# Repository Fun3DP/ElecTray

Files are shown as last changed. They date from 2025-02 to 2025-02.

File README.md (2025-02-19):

<p align="center">
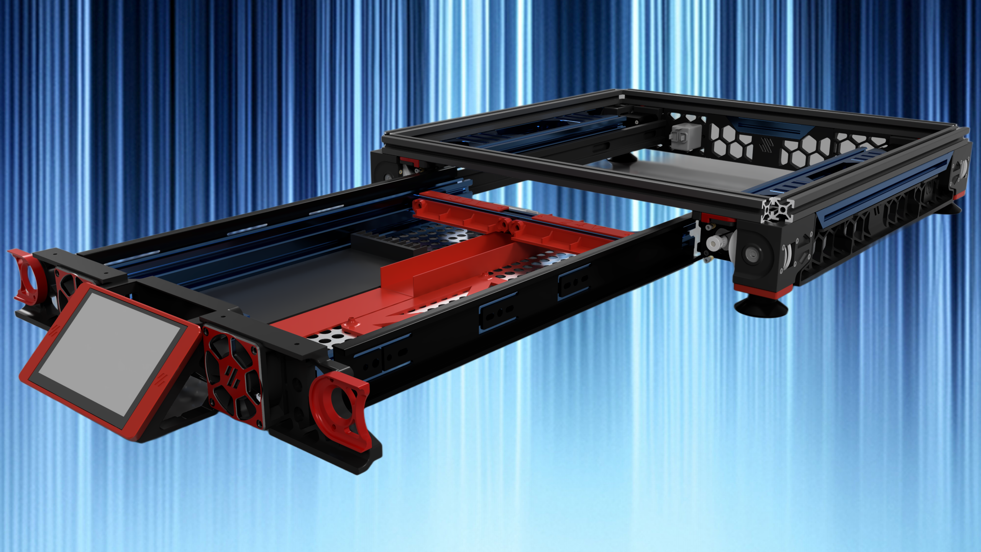
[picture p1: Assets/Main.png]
ElecTray
  
</p>

<p align="center"><b>A drawer mod for the Voron 2.4's electronic components (350mm only)</b>
</p>

<br>

<table>
<tr>
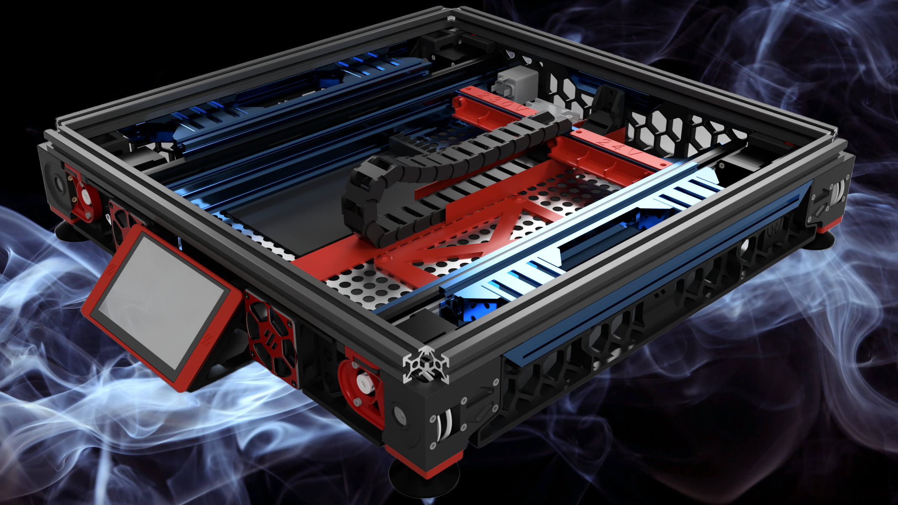
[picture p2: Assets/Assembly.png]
<td width=50%>
<td>
This is a personal project I’ve been working on for a while during my first Voron 2.4 build. I also have a heavily modified Sidewinder X2 printer, where easy access to electronics was my top priority during upgrades. With that in mind, I took the same approach when working on my Voron 2.4. This modification has already proven to be highly useful and convenient, as it has allowed me to quickly access and rectify certain issues as they arise.
<p>
</table>

## Table of Content
  
**[BOM](#bom)**<br>
**[STL](#stl)**<br>
**[CAD](#cad)**<br>
**[Brief instructional video](#brief-instructional-video)**<br>
**[Credits](#credits)**<br>
**[Changelog](#changelog)**<br>
**[Build Photos](#build-photos)**<br>

<br>

## BOM
<table>
<tr>
<td width=50%><img src="Assets/BOM.png" alt='ElecTray's BOM'></td>
<td>
<b>Things you will need:</b><br>
  - Drawer Runners 450mm (18")<br>
  - x60 M5x8 BHCS<br>
  - x12 M5x6 BHCS<br>
  - x4 M3x6 SHCS<br>
  - x52 M5 Spring T-Nuts<br>
  - x6 M3 Spring T-Nuts<br>
<b>Extrusions:</b><br>
  - x2 2020 335mm (threaded both sides)<br>
  - x1 2020 90mm (threaded both sides)<br>
  - x4 2060 50mm<br>
  - x2 2040 300mm<br>
  - x2 2040 467mm (threaded one side)<br>
  - x1 2020 261mm<br>
  - x1 2040 75mm (optional)*<br>
  - x24 90 Degree Angle Corner (at least x6 must be like this below):<br>
    https://ooznest.co.uk/product/90-degree-angle-corner/<br>
<b>Other:</b><br>
  - x6 WAGO (5way)**<br>
  - 467x302 tray (Mesh or Solid)<br>
  - Drag Chain (around 700mm length, not wider than 38mm - I used 10x30mm)<br>
  - 0.25 and 0.5 wires for extensions (Z motors, endstops etc.)<br>
</td>
</tr>
</table>
* I used this to mount the BTT HDMI5 to the mesh; however, you might prefer a different mount or a different mounting method.<br>
** The ones I used were knockoffs; therefore, the 'shelf' is slightly altered. For the original ones, you might want to use Voron's original design.<br>

<br>

## STL
<table>
<tr>
<td>
I have modified the necessary models, such as the skirting, to ensure they fit the modification properly. Additionally, I have designed and created new models as needed to facilitate the project's progress. These include an adapter for the Manta M8P board, slightly modified WAGO shelves to better suit the updated design, and a refined BTT HDMI 5" mount for improved compatibility. Each modification was made to enhance functionality, optimize integration, and ensure seamless assembly within the updated setup<br>
I recommend printing these parts with the same settings as Voron parts. I used ASA for mine, so I’d recommend using ABS or ASA.
<p>

[Take me to it!](STL)
</td>
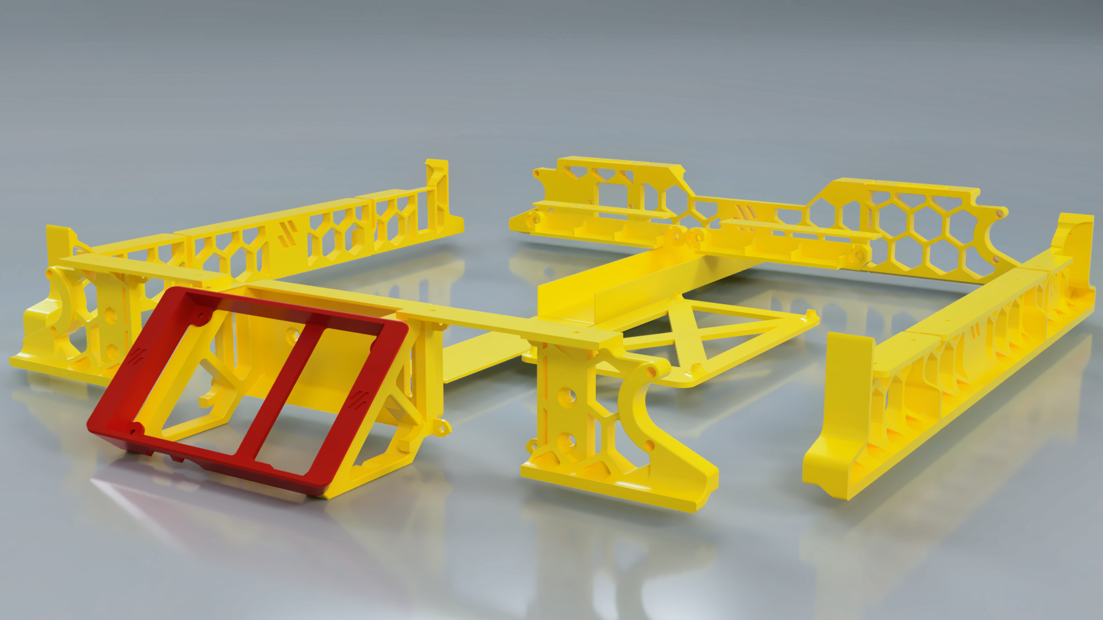
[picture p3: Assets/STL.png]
<td width=30%>
</tr>
</table>
<br>

## CAD
<table>
<tr>
<td>
I have created a CAD model for reference purposes only, allowing you to understand its construction, visualize its design, and see how it functions. While it is not intended for direct use, it provides a detailed overview of the mod’s structure and mechanics
<p>

[Take me to it!](CAD)
</td>
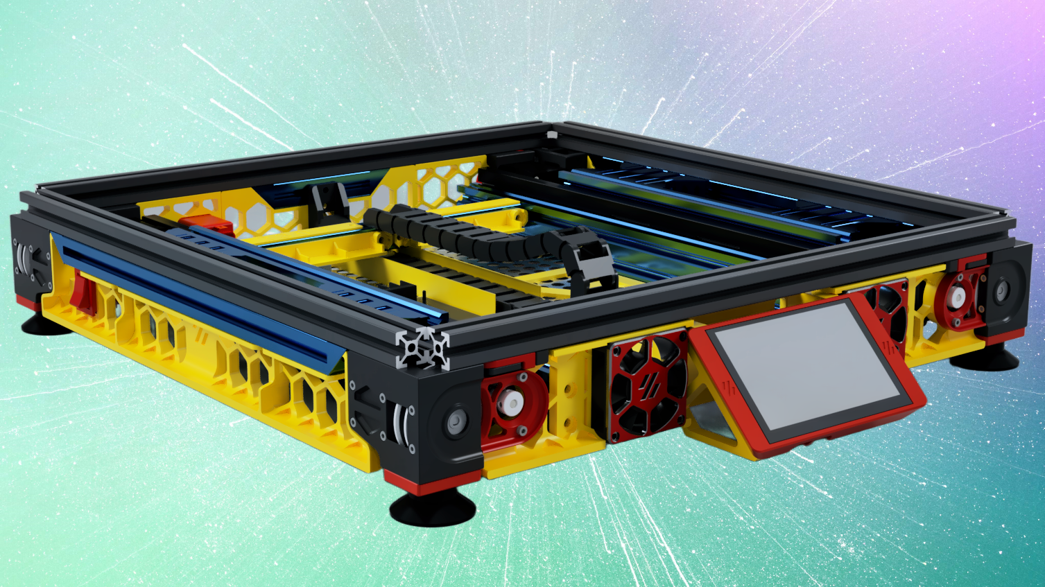
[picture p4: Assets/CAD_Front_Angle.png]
<td width=30%>
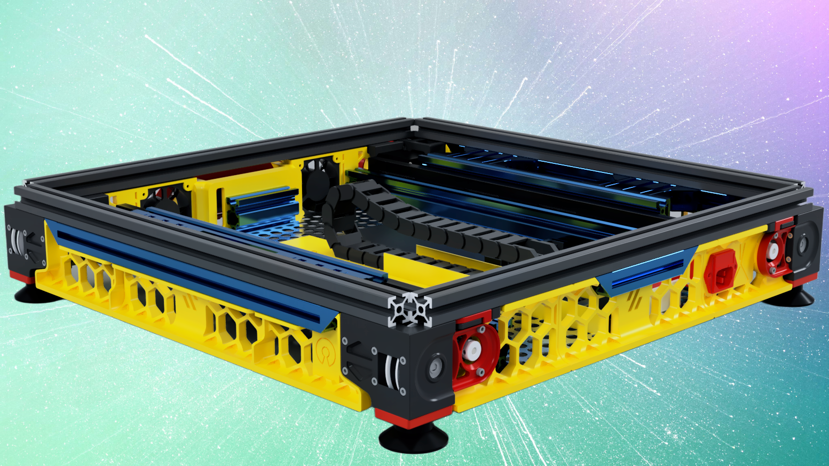
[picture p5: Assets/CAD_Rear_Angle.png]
<td width=30%>
</tr>
</table>

<p align="center">YELLOW components need printing as they are either new or modified.</p>
<p align="center">BLUE components need purchasing if you don't have them.</p>
<p align="center">RED components are stock models that don't require re-printing or purchasing.</p>
<br>

<br>

## Brief Instructional Video
<ul>
  <li> https://youtu.be/mlNWbNNKiyI
</ul>

## Credits
<ul>
  <li> Many thanks to @EDnation at (https://www.printables.com/@EDnation) for sharing his BTT HDMI5" v1.2 mount at https://www.printables.com/model/926845-btt-hdmi5-v12-display-mount-voron . I have modified one part to fit this modification.</li><br>
</ul>

## Changelog
<ul>
  <li>v1.0 - Initial Release (Enjoy!)
</ul>

<br>

## Build Photos
<div style="display: flex; flex-wrap: wrap; gap: 10px;">
    Build Photo 01
    Build Photo 02
    Build Photo 15
    Build Photo 03
    Build Photo 05
    Build Photo 06
    Build Photo 07
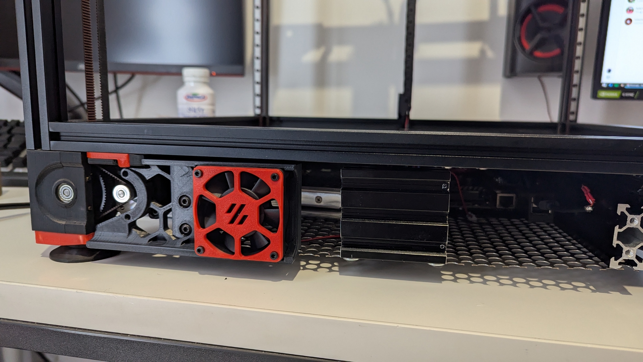
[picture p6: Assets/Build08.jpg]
Build Photo 08
    
    Build Photo 09
    Build Photo 10
    Build Photo 11
    Build Photo 12
    Build Photo 13
    Build Photo 14
    Build Photo 16
    Build Photo 17
</div>

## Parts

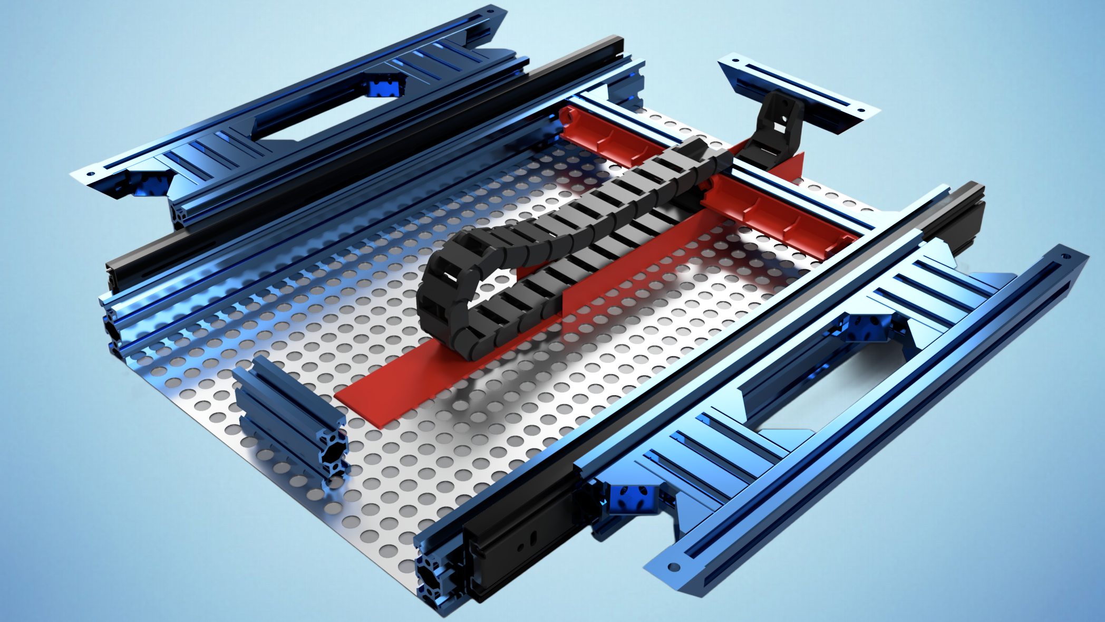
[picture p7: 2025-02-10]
Assets/BOM.png

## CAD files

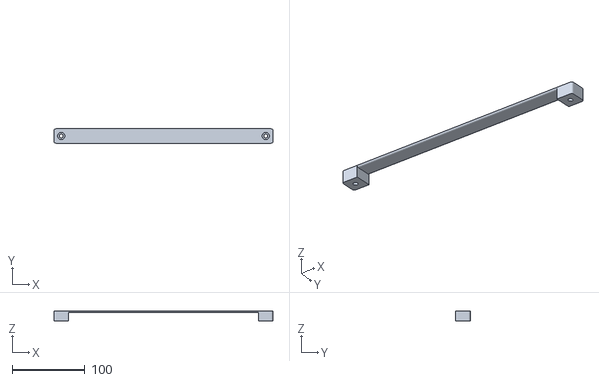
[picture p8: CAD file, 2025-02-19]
STL/Drag Chain Pressure Bar.stl
302.0 x 20.0 x 14.0

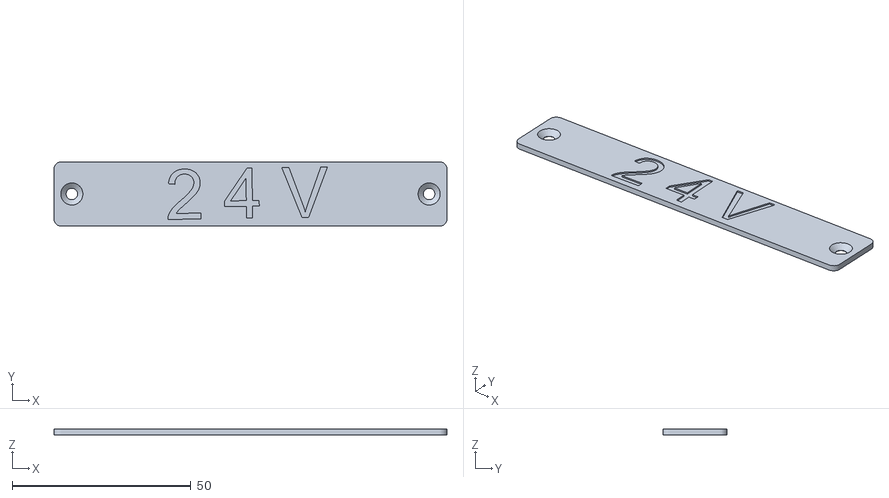
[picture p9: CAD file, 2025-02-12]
STL/Label 24v.stl
110.0 x 18.0 x 1.60

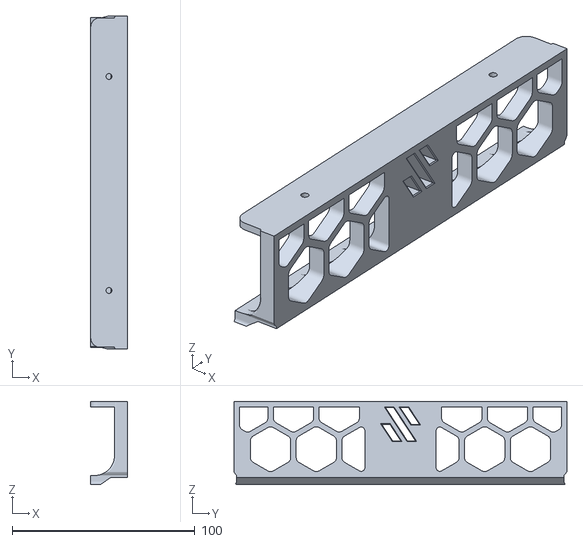
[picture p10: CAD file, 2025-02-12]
STL/Skirt - Left Side Center.stl
20.0 x 182.0 x 45.6

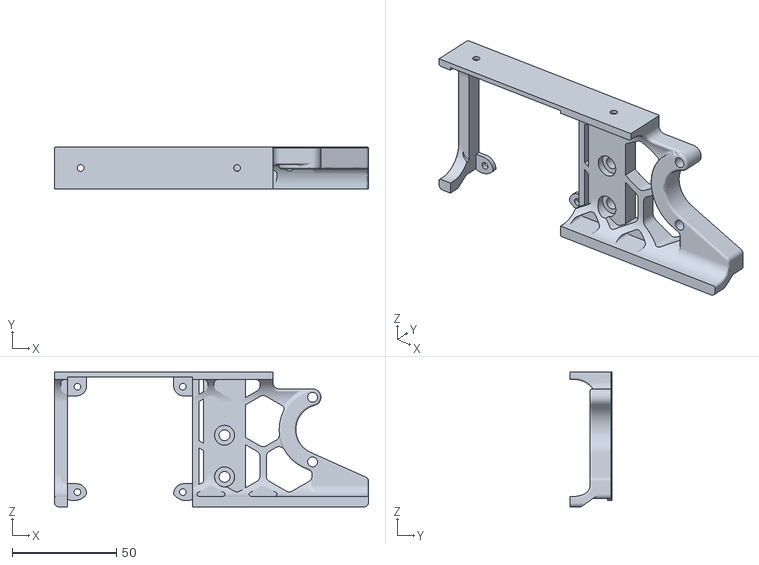
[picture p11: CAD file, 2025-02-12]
STL/Skirt - Front Right.stl
150.5 x 20.0 x 64.5

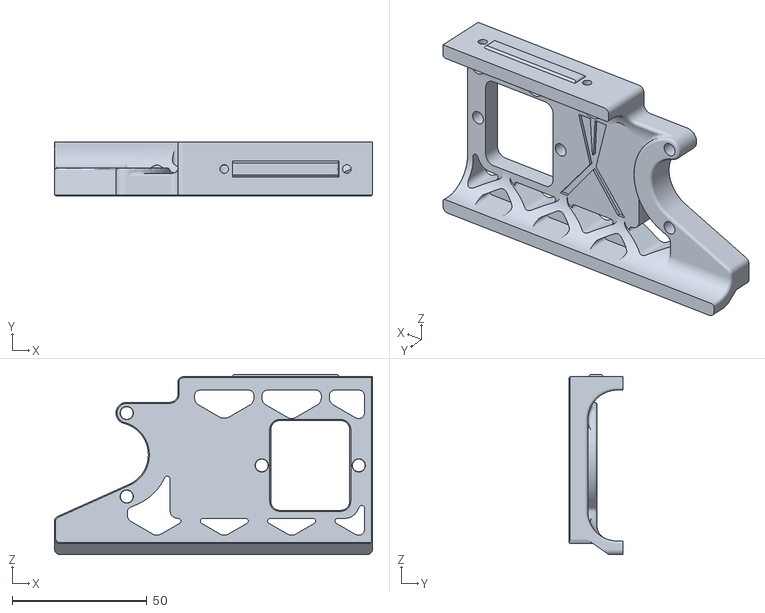
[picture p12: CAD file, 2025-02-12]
STL/Skirt - Rear Left.stl
118.0 x 20.0 x 66.8

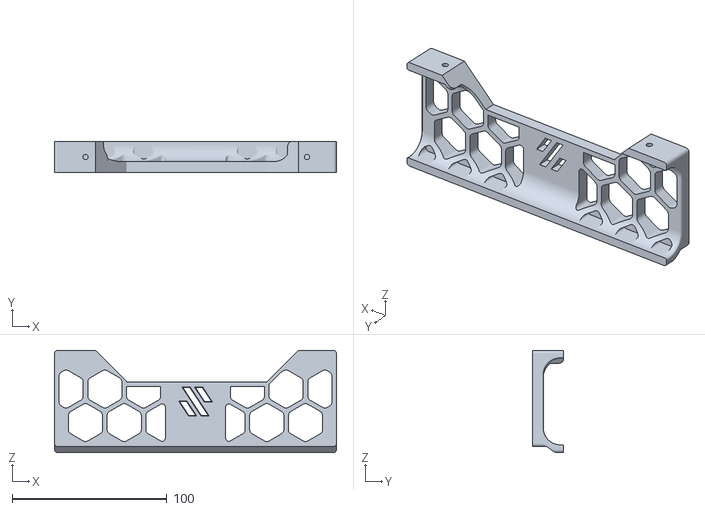
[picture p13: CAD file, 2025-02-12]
STL/Skirt - Rear Center.stl
182.0 x 20.0 x 66.0

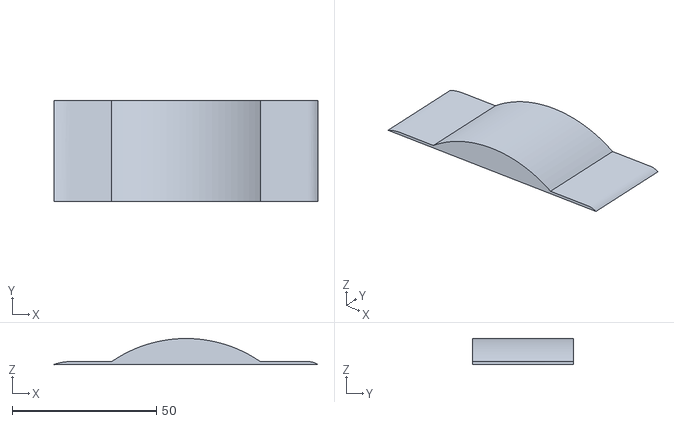
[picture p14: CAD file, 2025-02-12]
STL/Drag Chain Bump.stl
91.6 x 35.0 x 9.03

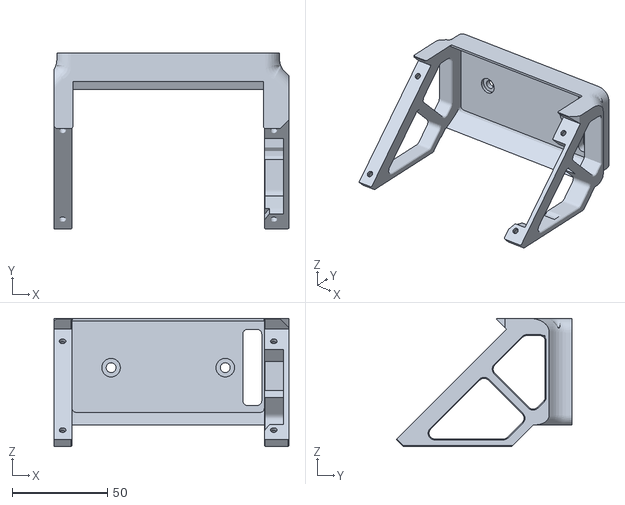
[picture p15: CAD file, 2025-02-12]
STL/BTT HDMI5 Mount Base (@EDnation - remixed).stl
123.5 x 92.4 x 67.3

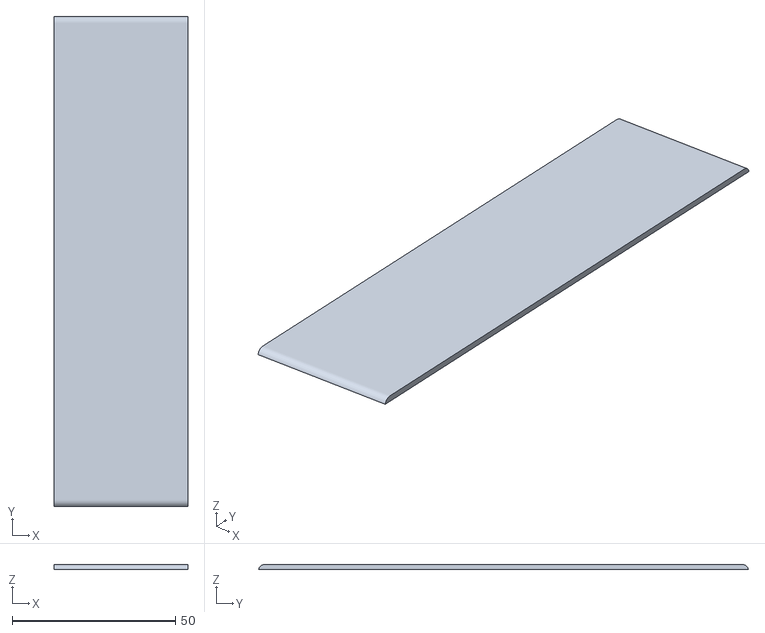
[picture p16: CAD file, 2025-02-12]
STL/Drag Chain Slide.stl
41.0 x 150.0 x 1.60

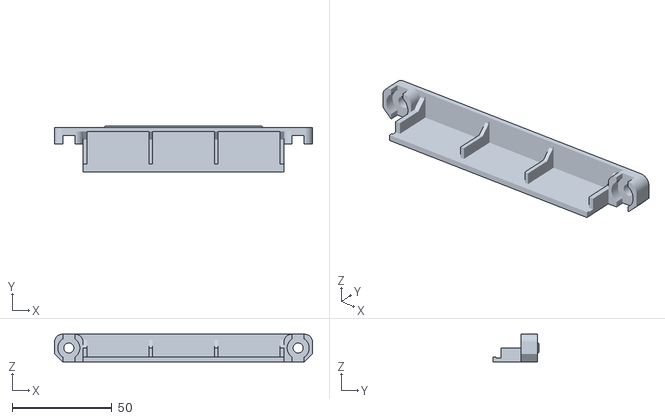
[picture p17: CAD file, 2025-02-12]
STL/WAGO Shelf 3x5way.stl
129.2 x 22.8 x 13.8

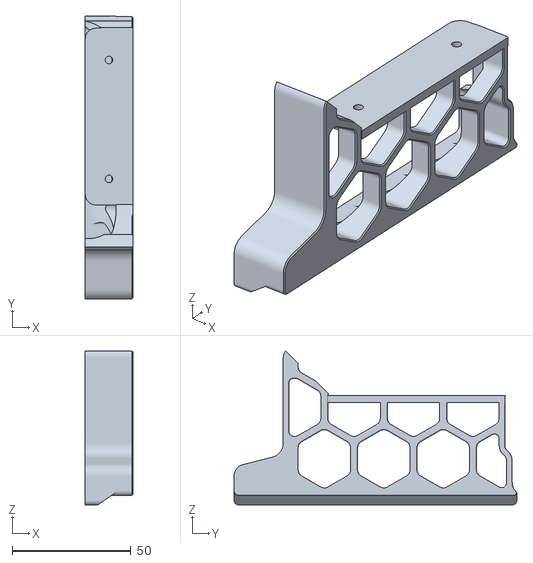
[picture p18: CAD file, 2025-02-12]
STL/Skirt - Left Side Front.stl
20.0 x 119.0 x 64.7

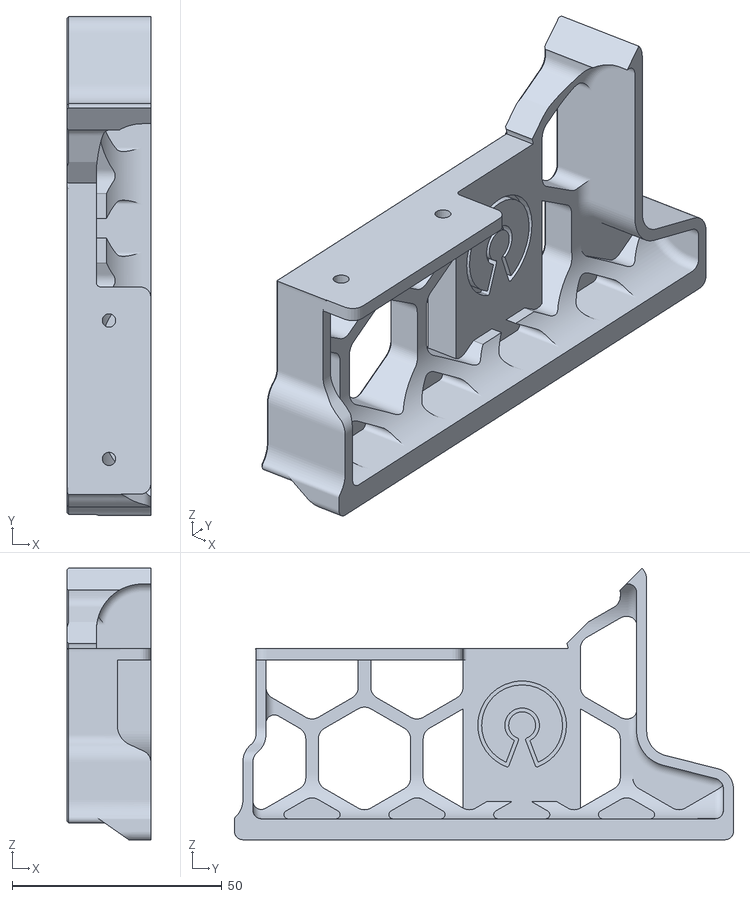
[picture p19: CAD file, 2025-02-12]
STL/Skirt - Right Side Rear.stl
20.0 x 119.0 x 64.8

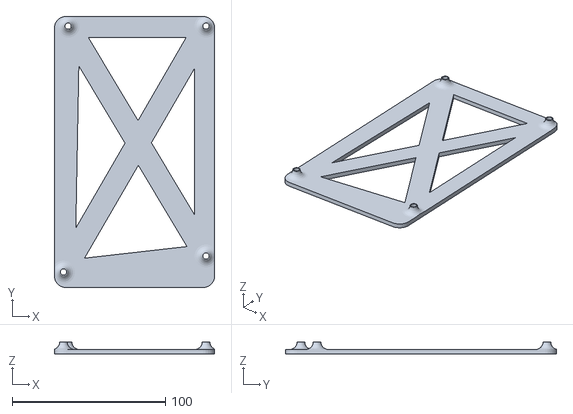
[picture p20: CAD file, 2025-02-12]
STL/BTT Manta M8P v2 Mount.stl
104.6 x 176.8 x 8.00

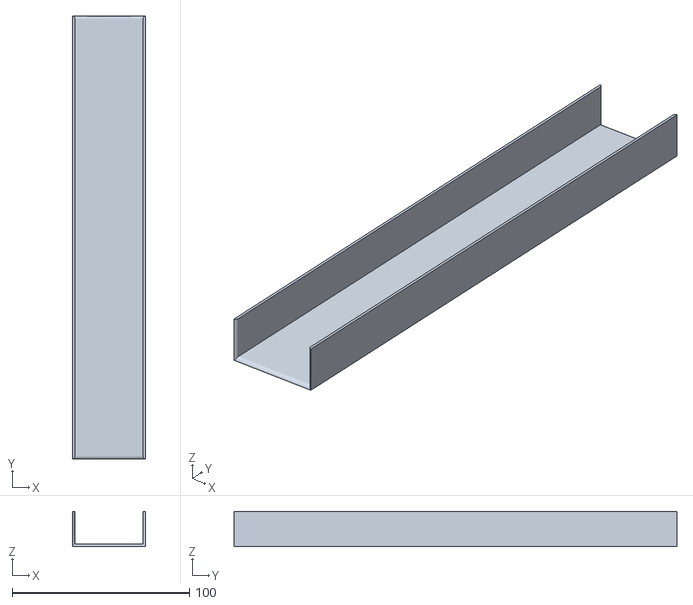
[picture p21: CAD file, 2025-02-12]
STL/Drag Chain Guide.stl
41.0 x 250.0 x 20.0

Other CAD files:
STL/Label 230v.stl
STL/Skirt - Right Side Center.stl
STL/Skirt - Front Left.stl
STL/Skirt - Right Side Front.stl
STL/BTT HDMI5 Screen Holder (@EDnation).stl
STL/Skirt - Left Side Rear (POWER ON).stl
STL/Skirt - Rear Right.stl

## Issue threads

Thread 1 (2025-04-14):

Can't fix 2020 bar.

sybux, 2025-04-14:
Hi,

as started discussion on YT, here is the next part.

As you can see on this picture, I'm too short with the angle.

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

I've so decided to make hole in the 2020 and use M5 T-Nut to fix the bar to the frame. At the end I won't be able to use your STL, but it will make the job at the end.

Fun3DP, 2025-04-14:
Hi @sybux

I have had a look into it...and to be honest only reason for that I can think of is the extrusion being too long. It is supposed to be 335mm long. The gap between the motors is 377mm which leaves you with 21mm gaps on both side of the extrusion for the 20mm angle corners with 1mm clearance on each side. I have verified this with Voron 2.4 350mm CAD as well.

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

sybux, 2025-04-14:
How stupid I am. I haven't checked size... The seller send me 350mm in stead of 335mm !! So, If I remove the extended size, it fits perfectly ! Sorry for this.

Closed 2025-04-14.

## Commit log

2025-02-12 STL Update
    [BTT HDMI5 Mount Base.stl, BTT HDMI5 Screen Holder.stl, BTT Manta M8P v2 Mount.stl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]
2025-02-18 Updated
    Added the Drag Chain Pressure Bar
2025-02-19 Update Drag Chain Pressure Bar.stl
    [Drag Chain Pressure Bar.stl]
2025-02-19 Update README.md
    BOM update:
    -extra x2 M5x6 BHCS added (for Drag Chain Pressure Bar)
    -extra x2 M5 Spring T-Nuts (for Drag Chain Pressure Bar)
2025-03-28 Create ElecTray.STEP_link
    ElecTray assembly .STEP file to allow any modifications.
